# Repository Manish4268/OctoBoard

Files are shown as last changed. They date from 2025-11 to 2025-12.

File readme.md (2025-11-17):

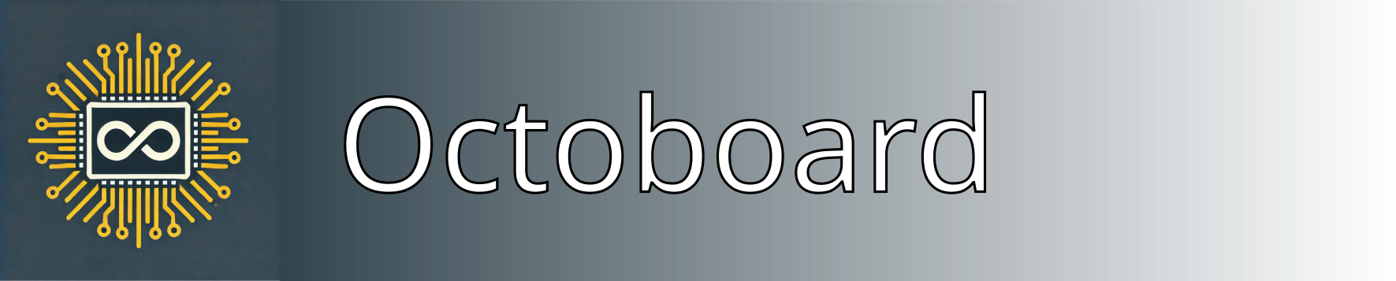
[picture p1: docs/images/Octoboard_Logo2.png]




# Maximum Power Point Tracker for Research-Level Solar Cells

## Overview
This repository documents the design, implementation, and operation of a massively parallel, low-cost Maximum Power Point Tracker (MPPT) for aging and degradation studies of perovskite solar cells. The system integrates custom-designed PCBs and software for efficient tracking and data logging.

**NEW: v2.0 System** - Production-ready system supporting 3 Raspberry Pis with up to 288 channels (72 samples). Features include configurable IV sweep intervals (1-1000 minutes), automated file transfer, persistent state management, optimized web dashboard, and automatic hardware detection for scalable deployment!

## Features

### Hardware

**Octoboards** (`Custom-designed PCBs`) - Source Measure Unit (SMU) functions
- 8 channels per board
- Modular and scalable design
- Support for multiple boards via I2C addressing
- **Current System**: 12 boards per Raspberry Pi = 96 channels
- **Total Capacity**: 3 RPis × 96 channels = **288 channels**

**Measurement Chuck**
- Allows up to 10 substrates (40 solar cells on "University of Marburg" cell layout)
- Aged in nitrogen atmosphere
- Compact design optimized for standard solar simulators
- Easy sample replacement without breaking atmosphere

### Software v2.0

**Dual-System Architecture:**

1. **RPi System** (`rpi_system/`)
   - Python-based control for 96 channels per RPi
   - Hourly automated IV sweeps
   - Real-time file transfer to Main PC
   - RESTful API for remote control
   - Sample configuration management (24 samples × 4 pixels)
   - **Simulation Mode** for development without hardware

2. **Main PC System** (`main_pc_system/`)
   - **Streamlit Dashboard** - Web-based control interface
   - **File Receiver** - Automated data collection from RPis
   - Real-time monitoring of all 3 RPis
   - Data visualization (IV curves, power curves)
   - Sample management and assignment
   - Data browser with file listings

**Key Capabilities:**
- ✅ 288 channels total (72 samples, 4 pixels each)
- ✅ Configurable IV sweep intervals (1-1000 minutes per sample)
- ✅ Automatic hardware detection (supports 1-12 Octoboards per RPi)
- ✅ Persistent state management via status files
- ✅ Optimized dashboard with pagination for 288+ channels
- ✅ Production-ready deployment with systemd service
- ✅ Comprehensive beginner's guide for Raspberry Pi setup
- ✅ Hourly IV sweep generation (1 file per channel)
- ✅ Automatic LAN-based file transfer
- ✅ Organized data storage: `SampleID/pixel/IV_timestamp.csv`
- ✅ Real-time dashboard monitoring
- ✅ Simulation mode for Windows development
- ✅ RESTful API control
- ✅ Multi-board management

### Integration
- Full Raspberry Pi compatibility (tested on RPi 4)
- Windows development support via simulation mode
- Network communication (LAN, no internet required)
- Modular and extensible architecture

## Repository Structure
```plaintext
├── docs/                                    # Documentation and images
├── hardware/                                # PCB designs and CAD files
│   ├── Measurement Chuck Housing CAD Design/
│   ├── Measurement Chuck PCB Design/
│   └── Octoboard PCB Design/
│   │   └── gerber.zip
│   ├── Octoboard PCB Design/
│   │   ├── DAC.kicad_sch
│   │   ├── octoboard.kicad_pcb
│   │   ├── octoboard.kicad_prl
│   │   ├── octoboard.kicad_pro
│   │   └── octoboard.kicad_sch
├── software/
│   ├── hardware/
│   │   ├── __init__.py
│   │   ├── channel.py
│   │   ├── constants.py
│   │   ├── i2c.py
│   │   ├── manager.py
│   │   ├── oboard.py
│   │   └── sdac.py
│   ├── tests/
│   │   ├── test_hardware.py
│   │   ├── test_logger.py
│   │   └── test_tracker.py
│   ├── __init__.py
│   ├── cli.py
│   ├── logger.py
│   ├── requirements.txt
│   └── setup.py
└── README.md
```

## Documentation

### 1. Hardware

#### **1.1 Octoboard**
The Octoboard is a custom-designed PCB that forms the core of the MPPT system, providing capabilities for maximum power point tracking in solar cell testing and evaluation.

**Key Components:**
- **MCP23017**: 16-bit I2C I/O expander for digital control
- **MCP4728**: 4-channel DAC for voltage control
- **ADS1115**: 16-bit ADC for precision measurement
- **LMV324**: Quad operational amplifiers for signal conditioning
- **74HC4051**: Analog multiplexers for efficient channel selection

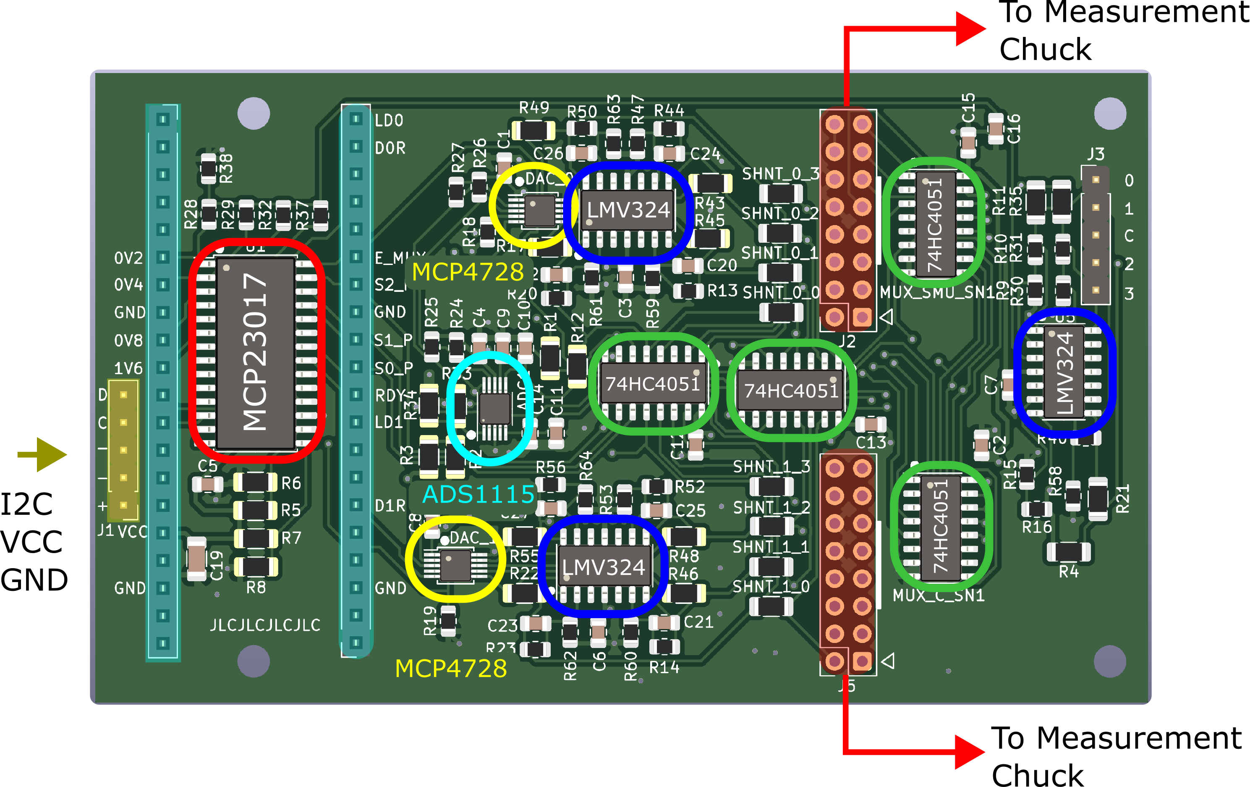
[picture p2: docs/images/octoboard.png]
Octoboard PCB Layout


#### Component Specifications

| Component | Type | Key Specifications | Datasheet |
|---|---|---|---|
| MCP4728 | DAC | 12-bit, 4-channel, I2C | [Datasheet](http://ww1.microchip.com/downloads/en/devicedoc/22187e.pdf) |
| ADS1115 | ADC | 16-bit, 4-channel, I2C | [Datasheet](https://www.ti.com/lit/gpn/ads1115) |
| LMV324 | Op-Amp | Rail-to-rail, low power | [Datasheet](https://www.onsemi.com/download/data-sheet/pdf/lmv321-d.pdf) |
| 74HC4051 | Multiplexer | 8-channel analog | [Datasheet](https://assets.nexperia.com/documents/data-sheet/74HC_HCT4051.pdf) |
| MCP23017 | I/O Expander | 16-bit, I2C | [Datasheet](https://ww1.microchip.com/downloads/aemDocuments/documents/APID/ProductDocuments/DataSheets/MCP23017-Data-Sheet-DS20001952.pdf) |

#### System Architecture
The MPPT system is designed with a hierarchical structure:
1. Central Raspberry Pi controller
2. Multiple Octoboards (8 channels each)
3. I2C communication backbone
4. Integrated sample holder with thermal management

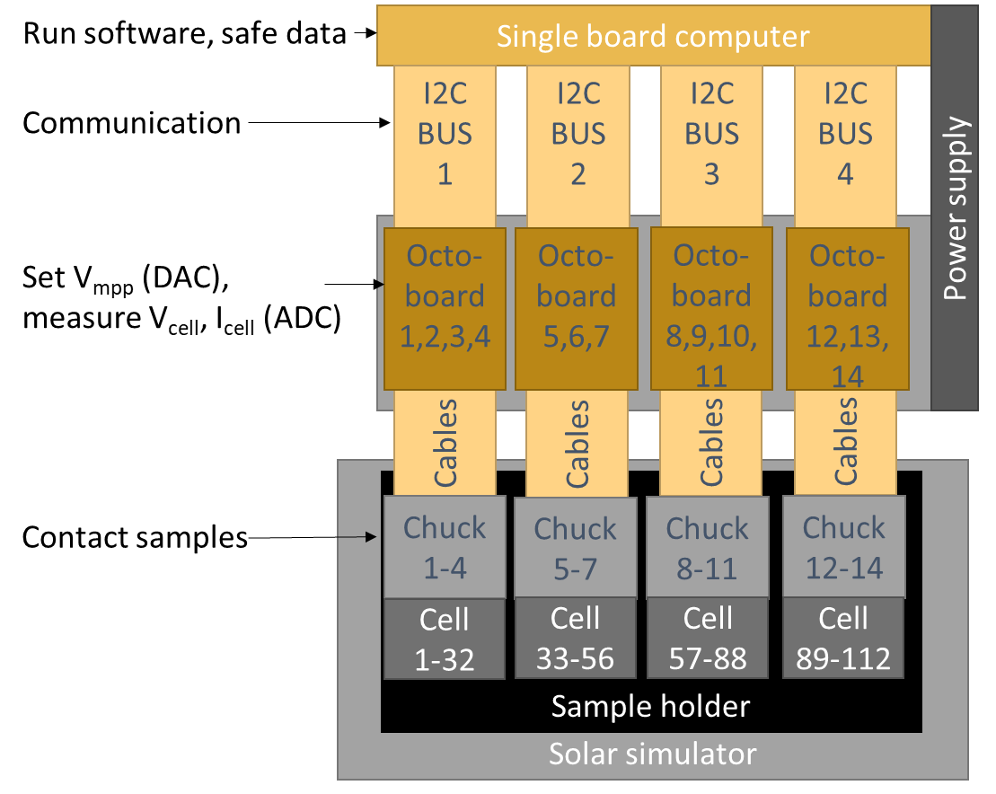
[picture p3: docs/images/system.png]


#### **1.2 Measurement Chuck**
The Measurement Chuck allows up to 10 substrates (40 solar cells on a "University of Marburg" cell layout) to be aged under a nitrogen atmosphere.
Due to its compact design, up to eight measurement chucks can be fit in a Solaronix SOLIXON A-45 solar simulator. 

**Operation & Handling**
To replace the substrates inside a chuck:
1. Disconnect the flat ribbon cables and nitrogen supply hoses (quick-connect couplings ensure that the remaining substrates stay in an N₂ atmosphere).
2. Transfer the chuck to a glovebox, where the cells can be exchanged by loosening the screws as shown in the video below.
3. Reinsert the newly equipped chuck into the sun simulator and attach it to the cables and supply hoses. 

<div style="display: flex; justify-content: flex-start;">
    
</div>

### 2. Software v2.0

## Quick Start

### System Components

**1. Raspberry Pi System** (`rpi_system/`)
- Controls 96 channels (12 Octoboards)
- Runs hourly IV sweeps automatically
- Transfers data to Main PC via LAN
- RESTful API for remote control

**2. Main PC System** (`main_pc_system/`)
- Web dashboard (Streamlit) for control
- File receiver for automated data collection
- Real-time monitoring of all RPis
- Data visualization and analysis

### Installation & Setup

#### Main PC System

```powershell
cd main_pc_system
.\start.bat  # Automatic setup and launch
```

Opens:
- File Receiver at `http://192.168.1.100:8000`
- Dashboard at `http://localhost:8501`

#### Raspberry Pi System

```bash
cd rpi_system

# For actual hardware
python api_server.py

# For simulation/testing (Windows)
$env:OCTOBOARD_SIMULATION="True"
python api_server.py
```

### Complete Documentation

- **[Main PC System README](main_pc_system/README.md)** - Setup, API endpoints, usage
- **[RPi System README](rpi_system/README.md)** - Hardware control, configuration
- **[Testing Guide](TESTING_GUIDE.md)** - Complete end-to-end testing procedures
- **[Project Structure](PROJECT_STRUCTURE.md)** - System architecture overview

## System Capacity

| Metric | Value |
|---|---|
| Raspberry Pis | 3 |
| Octoboards per RPi | 12 |
| Channels per RPi | 96 |
| **Total Channels** | **288** |
| Samples per RPi | 24 (4 pixels each) |
| **Total Sample Capacity** | **72** |
| IV Sweep Frequency | Every 1 hour |
| Files Generated | 96 per hour per RPi |

## Network Configuration

| Device | IP Address | Port | Role |
|---|---|---|---|
| Main PC | 192.168.1.100 | 8000 (Receiver) | Control center |
| Main PC | 192.168.1.100 | 8501 (Dashboard) | Web interface |
| RPi 1 | 192.168.1.101 | 8001 | Channels 0-95 |
| RPi 2 | 192.168.1.102 | 8001 | Channels 0-95 |
| RPi 3 | 192.168.1.103 | 8001 | Channels 0-95 |

## Data Flow

```
┌─────────────┐
│   RPi 1-3   │ ──► Hourly IV Sweeps (96 channels each)
│ (Octoboards)│       │
└─────────────┘       │
                      ▼
              ┌──────────────┐
              │  Generate    │ ──► 4 CSV files per sample
              │  IV Files    │       (pixels a, b, c, d)
              └──────────────┘
                      │
                      ▼
              ┌──────────────┐
              │  HTTP POST   │ ──► Transfer over LAN
              │  to Main PC  │
              └──────────────┘
                      │
                      ▼
         ┌────────────────────────┐
         │  Main PC File Receiver │
         │  Organizes & Stores    │
         └────────────────────────┘
                      │
                      ▼
    C:/OctoBoard_Data/
    └── SampleID/
        ├── a/
        │   └── IV_timestamp.csv
        ├── b/
        ├── c/
        └── d/
```

### 2. Software (Legacy)

#### Installation

1. Clone the repository:
```bash
git clone https://github.com/H2020DiamondEU/octoboard.git
cd octoboard
```

2. Install dependencies:
```bash
pip install -r software/requirements.txt
```

3. Install the package:
```bash
pip install -e .
```

#### Usage

1. Basic operation:
```python
from software import OBoardManager

# Initialize manager with I2C bus number
manager = OBoardManager(i2c_num=1)

# Start MPP tracking on all channels
manager.cycle_all_channels(iterations_per_channel=10)
```

2. Command-line interface:
```bash
python -m software.cli 1  # Start tracking on I2C bus 1
```

### 3. Data Management

Data is stored in CSV format with the following structure:
- Location: `data/[board_id]_channel_[n]_data.csv`
- Format: timestamp, voltage, current, power, temperature

### 4. Troubleshooting

Common issues and solutions:
1. I2C Communication Errors
   - Check bus number and device addresses
   - Verify cable connections
   - Check for address conflicts

2. Measurement Instability
   - Verify power supply stability
   - Check contact resistance

## License
This project is licensed under the MIT License. See `LICENSE` for details.

## Links
- [Project Website](https://diamond-horizon.eu/)
- [European Commission Project Page](https://cordis.europa.eu/project/id/101084124)
- [Deliverable Documentation](https://ec.europa.eu/research/participants/documents/downloadPublic?documentIds=080166e50d1470c5&appId=PPGMS)

## Contact
For further information on integrating this measurement system into your PV lab, please contact:
- **Lukas Wagner**, Physics of Solar Energy Conversion Group, Philipps-University Marburg, Germany.
- **Clemens Baretzky**, Fraunhofer Institute for Solar Energy Systems ISE, Germany.

<div style="display: flex; justify-content: flex-start;">
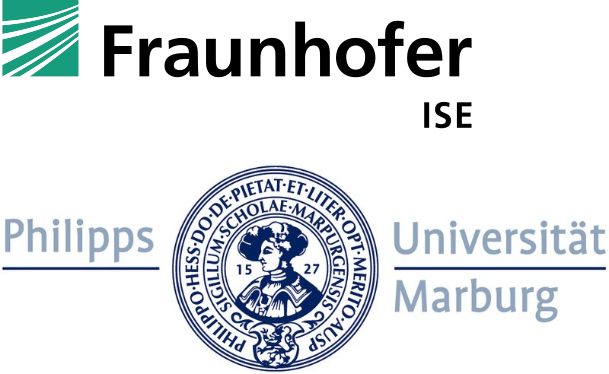
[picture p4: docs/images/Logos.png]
    
</div> 

## Acknowledgments
This design was developed at the **University of Marburg** and **Fraunhofer ISE**.
The project is funded by the European Union in the Horizon 2.5. Climate, Energy and Mobility programme under Grant Agreement No. 101084124. Views and opinions expressed are however those of the author(s) only and do not necessarily reflect those of the European Union. Neither the European Union nor the granting authority can be held responsible for them.

<div style="display: flex; justify-content: flex-start;">
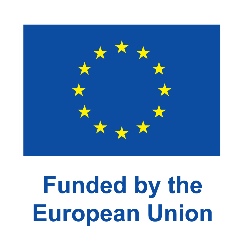
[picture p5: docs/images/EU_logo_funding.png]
    
</div>

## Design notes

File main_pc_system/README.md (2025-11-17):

# OctoBoard Main PC System

Control center for managing 3 Raspberry Pis with 288 channels (72 samples) for solar cell testing.

## System Overview

- **Total Capacity**: 3 RPis × 96 channels = 288 channels
- **Sample Capacity**: 72 samples (24 per RPi, 4 pixels per sample)
- **Data Generation**: Hourly IV sweeps per channel (96 files/hour/RPi)
- **Communication**: LAN-based REST API (192.168.1.x network)

## Components

### 1. File Receiver (`file_receiver.py`)
FastAPI server that receives IV measurement files from RPis.

**Features:**
- HTTP POST endpoint for file uploads
- Automatic directory structure creation
- File validation and statistics tracking
- Sample management endpoints

**Endpoints:**
- `POST /upload` - Receive IV files from RPis
- `GET /ping` - Health check
- `GET /stats` - Get receiver statistics
- `GET /samples` - List all samples
- `GET /sample/{sample_id}` - Get files for specific sample

### 2. Dashboard (`dashboard.py`)
Streamlit-based web interface for system control and monitoring.

**Features:**
- Real-time RPi status monitoring
- New sample measurement configuration
- Active measurement management
- Data browser with file listings
- IV curve visualization with Plotly

**Tabs:**
1. **New Measurement** - Configure and start new sample measurements
2. **Active Measurements** - Monitor and control running measurements
3. **Data Browser** - Browse stored IV files by sample/pixel
4. **Data Visualization** - Plot IV and power curves

## Installation

### Requirements
- Python 3.9 or higher
- Windows 10/11 (or Linux/Mac with path adjustments)

### Setup

```powershell
# Navigate to main_pc_system directory
cd C:\Users\ManishJadhav\OctoBoard\main_pc_system

# Create virtual environment
python -m venv venv

# Activate virtual environment
.\venv\Scripts\Activate.ps1

# Install dependencies
pip install -r requirements.txt
```

## Running the System

### 1. Start File Receiver

```powershell
# Terminal 1
cd C:\Users\ManishJadhav\OctoBoard\main_pc_system
.\venv\Scripts\Activate.ps1
python -m uvicorn file_receiver:app --host 0.0.0.0 --port 8000
```

**Expected Output:**
```
INFO:     Started server process
INFO:     Waiting for application startup.
INFO:     Application startup complete.
INFO:     Uvicorn running on http://0.0.0.0:8000
```

### 2. Start Dashboard

```powershell
# Terminal 2 (new terminal)
cd C:\Users\ManishJadhav\OctoBoard\main_pc_system
.\venv\Scripts\Activate.ps1
streamlit run dashboard.py
```

**Expected Output:**
```
You can now view your Streamlit app in your browser.
Local URL: http://localhost:8501
Network URL: http://192.168.1.100:8501
```

## Network Configuration

### Main PC
- **IP Address**: `192.168.1.100`
- **File Receiver**: Port `8000`
- **Dashboard**: Port `8501`

### Raspberry Pis
- **RPi 1**: `192.168.1.101:8001` (Channels 0-95, Samples 1-24)
- **RPi 2**: `192.168.1.102:8001` (Channels 0-95, Samples 25-48)
- **RPi 3**: `192.168.1.103:8001` (Channels 0-95, Samples 49-72)

## Data Storage

### Directory Structure
```
C:/OctoBoard_Data/
├── Sample_001/
│   ├── a/
│   │   ├── IV_20240101_120000.csv
│   │   ├── IV_20240101_130000.csv
│   │   └── ...
│   ├── b/
│   ├── c/
│   └── d/
├── Sample_002/
│   ├── a/
│   ├── b/
│   ├── c/
│   └── d/
└── ...
```

### File Format
Each IV file is a CSV with columns:
- `voltage` - Applied voltage (V)
- `current` - Measured current (A)
- `power` - Calculated power (W)
- `timestamp` - Measurement timestamp

## Usage Guide

### Starting a New Measurement

1. Open dashboard at `http://localhost:8501`
2. Go to **"New Measurement"** tab
3. Fill in sample information:
   - Sample ID (unique identifier)
   - Cell area (cm²)
   - Current limit (mA)
4. Configure IV sweep parameters:
   - Start/Stop voltage
   - Voltage step
   - Settle time
5. Select RPi and channel slot
6. Click **"Start Measurement"**

### Monitoring Active Measurements

1. Go to **"Active Measurements"** tab
2. View all running measurements across RPis
3. Stop measurements using **"Stop"** button

### Browsing Data

1. Go to **"Data Browser"** tab
2. Select sample from dropdown
3. View file counts for each pixel (a, b, c, d)
4. See latest file timestamps

### Visualizing Data

1. Go to **"Data Visualization"** tab
2. Select sample and pixel
3. Choose specific IV file to plot
4. View IV curve and power curve
5. See key metrics (max power, voltage at MPP)

## Troubleshooting

### File Receiver Not Starting
```powershell
# Check if port 8000 is in use
netstat -ano | findstr :8000

# Kill process if needed
taskkill /PID <process_id> /F
```

### Dashboard Cannot Connect to RPis
- Verify RPis are powered on and running API servers
- Check network connectivity: `ping 192.168.1.101`
- Ensure firewall allows ports 8001-8003
- Check RPi API server logs

### No Data Appearing
- Verify file receiver is running on port 8000
- Check `C:/OctoBoard_Data/` directory permissions
- Review file receiver logs for upload errors
- Ensure RPis have correct Main PC IP configured

### Dashboard Shows Offline RPis
- Confirm RPi API servers are running
- Test RPi endpoints manually:
  ```powershell
  curl http://192.168.1.101:8001/status
  ```
- Check network switches and cables
- Verify IP addresses in dashboard match RPi configuration

## API Documentation

### File Receiver API

**POST /upload**
```json
{
  "file": "<binary file data>",
  "rpi_id": "rpi_1",
  "sample_id": "Sample_001",
  "pixel": "a"
}
```

**Response:**
```json
{
  "status": "success",
  "message": "File uploaded successfully",
  "file_path": "C:/OctoBoard_Data/Sample_001/a/IV_20240101_120000.csv",
  "file_size": 12345
}
```

**GET /stats**
```json
{
  "files_received": 1250,
  "total_bytes": 15728640,
  "last_received": "2024-01-01T12:00:00"
}
```

## Development Notes

### Testing Without RPis
The system can be tested with mock RPis running in simulation mode:

```powershell
# Start mock RPi (simulate RPi 1)
cd ..\rpi_system
$env:OCTOBOARD_SIMULATION="True"
python api_server.py
```

### Customization

**Change data directory:**
Edit `dashboard.py` and `file_receiver.py`:
```python
DATA_ROOT = Path("D:/MyData")  # Change path
```

**Modify RPi IP addresses:**
Edit `dashboard.py`:
```python
RPIS = {
    "RPi 1": {"url": "http://192.168.2.101:8001", "id": "rpi_1"},
    # ...
}
```

**Adjust sweep interval:**
Edit `rpi_system/api_server.py`:
```python
IV_SWEEP_INTERVAL_HOURS = 2  # Change from 1 to 2 hours
```

## Performance

- **File Transfer Rate**: ~100 files/second
- **Dashboard Refresh**: ~1-2 seconds for 3 RPis
- **Storage**: ~10 KB per IV file, ~24 MB/day/sample (hourly sweeps)
- **Memory Usage**: Dashboard ~200 MB, File Receiver ~100 MB

## Safety Features

- File validation before storage
- Automatic directory creation
- Graceful handling of offline RPis
- Statistics tracking for monitoring
- No internet dependency (LAN only)

## Future Enhancements

- Database integration (SQLite/PostgreSQL)
- Email alerts for measurement completion
- Automatic data backup
- Multi-file IV curve comparison
- Export to Excel/PDF reports
- User authentication
- Measurement scheduling
- Data compression for long-term storage

## Support

For issues or questions:
1. Check troubleshooting section above
2. Review logs in terminal windows
3. Verify network configuration
4. Test individual components separately

## License

Part of OctoBoard project - Solar cell MPPT testing system.

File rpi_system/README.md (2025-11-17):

# Raspberry Pi System

This code runs on each Raspberry Pi to control 96 channels (12 Octoboards).

## Hardware Configuration

- **12 Octoboards** per Raspberry Pi
- **96 channels** total (12 × 8)
- **24 samples** capacity (each sample uses 4 channels for 4 pixels)
- **I2C Bus:** Typically bus 1
- **I2C Address Offsets:** 0-11 (for 12 boards)

## Features

- Controls 96 channels via 12 Octoboards
- Handles 24 samples simultaneously (4 pixels each)
- Hourly IV sweep generation (every 1 hour)
- Automatic file transfer to Main PC via LAN
- REST API for remote control from Main PC
- Simulation mode for testing without hardware

## Installation

```bash
cd rpi_system/
pip install -r requirements.txt
```

## Configuration

Set environment variables:

```bash
export RPI_ID=rpi_1              # or rpi_2, rpi_3
export OCTOBOARD_I2C_BUS=1       # I2C bus number
export MAIN_PC_IP=192.168.1.100  # Main PC IP address
export API_PORT=8001              # API server port
```

## Running

### Production Mode (on Raspberry Pi):

```bash
python api_server.py
```

### Simulation Mode (for testing on Windows/Mac):

```bash
export OCTOBOARD_SIMULATION=True
python api_server.py
```

## API Endpoints

### Status and Info

- `GET /` - API information
- `GET /status` - RPi status
- `GET /channels` - List all 96 channels (24 sample slots)

### Measurements

- `POST /measurement/start` - Start measuring a sample
- `POST /measurement/stop/{sample_id}` - Stop measuring a sample
- `GET /measurement/{sample_id}` - Get sample measurement status

## Sample Configuration

Each sample occupies 4 consecutive channels for 4 pixels (a, b, c, d):

```json
{
  "sample_id": "Sample_001",
  "start_channel": 0,
  "cell_area": 0.09,
  "current_limit": 50,
  "start_voltage": 0.0,
  "stop_voltage": 1.2,
  "voltage_step": 0.01,
  "settle_time": 0.1,
  "measurement_type": "iv_sweep"
}
```

### Channel Allocation:

- Sample 1: channels 0-3 (pixels a, b, c, d)
- Sample 2: channels 4-7 (pixels a, b, c, d)
- ...
- Sample 24: channels 92-95 (pixels a, b, c, d)

## Hourly IV Sweeps

- Configured in `software/hardware/constants.py`: `IV_SWEEP_INTERVAL_HOURS = 1`
- Runs IV sweep for all active samples every hour
- Generates timestamped files: `IV_2025-11-17_10-00-00.csv`
- Automatically transfers files to Main PC

## File Transfer

Files are sent to Main PC via HTTP POST:
- **URL:** `http://{MAIN_PC_IP}:8000/upload`
- **Method:** POST with multipart/form-data
- **Timeout:** 30 seconds (configurable)

## Directory Structure

```
rpi_system/
├── api_server.py              # Main API server
├── software/                  # Hardware control code
│   ├── __init__.py
│   ├── cli.py
│   ├── logger.py
│   └── hardware/
│       ├── channel.py         # Single channel control
│       ├── oboard.py          # Single board (8 channels)
│       ├── manager.py         # Multi-board manager
│       ├── constants.py       # Configuration
│       ├── i2c.py             # I2C interface
│       ├── sdac.py            # Software DAC
│       └── mock_hardware.py   # Simulation mode
├── requirements.txt           # Dependencies
└── README.md                  # This file
```

## Troubleshooting

### RPi can't detect all 12 boards:
```bash
# Check I2C devices
i2cdetect -y 1
```

### Main PC connection fails:
- Verify Main PC file receiver is running
- Check network connectivity: `ping 192.168.1.100`
- Check firewall settings

### Simulation mode not working:
```bash
# Make sure simulation flag is set
echo $OCTOBOARD_SIMULATION
export OCTOBOARD_SIMULATION=True
```

## Network Requirements

- **LAN/Ethernet connection** (no internet required)
- **Static IP recommended:** 192.168.1.101-103
- **Open Ports:**
  - 8001: RPi API server
  - 8000: Main PC file receiver (outgoing)

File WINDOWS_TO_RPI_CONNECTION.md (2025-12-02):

# 🔌 How to Connect to Raspberry Pi from Windows

## 📋 What You Need

### Hardware
- ✅ Raspberry Pi (any model with GPIO pins)
- ✅ Ethernet cable connecting RPi to your laptop/network
- ✅ Power supply for RPi (5V, 2.5A+)
- ✅ MicroSD card with Raspberry Pi OS installed
- ⚠️ Optional: HDMI monitor + keyboard (for initial setup)

### Software for Windows
We'll install these step by step below:
1. **PuTTY** - SSH client to connect to RPi
2. **WinSCP** - File transfer tool
3. **VS Code** (optional) - For editing code remotely
4. **IP Scanner** - To find your RPi

---

## 🎯 Step 1: Install Required Software

### Install PuTTY (SSH Client)

**What is PuTTY?**
PuTTY lets you control the Raspberry Pi using command line from your Windows PC.

**Download:**
1. Go to: https://www.putty.org/
2. Click: **Download PuTTY**
3. Download: `putty-64bit-0.xx-installer.msi`
4. Run the installer
5. Click **Next** → **Install** → **Finish**

**Where it is:** Start Menu → PuTTY → PuTTY

---

### Install WinSCP (File Transfer)

**What is WinSCP?**
WinSCP lets you drag-and-drop files between Windows and Raspberry Pi (like Windows Explorer).

**Download:**
1. Go to: https://winscp.net/eng/download.php
2. Download: **Installation package**
3. Run installer
4. Click **Next** → **Next** → **Install** → **Finish**

**Where it is:** Start Menu → WinSCP

---

### Install Advanced IP Scanner (Find RPi)

**What is Advanced IP Scanner?**
Scans your network to find all connected devices, including your Raspberry Pi.

**Download:**
1. Go to: https://www.advanced-ip-scanner.com/
2. Click **Download**
3. Run `advanced_ip_scanner.exe`
4. No installation needed - it runs directly!

---

### Install VS Code with Remote SSH (Optional, for Advanced Users)

**What is VS Code Remote SSH?**
Edit code on Raspberry Pi directly from VS Code on Windows - super convenient for debugging!

**Download VS Code:**
1. Go to: https://code.visualstudio.com/
2. Download Windows version
3. Install with default settings

**Install Remote SSH Extension:**
1. Open VS Code
2. Click Extensions icon (left sidebar, squares icon)
3. Search: **Remote - SSH**
4. Click **Install** on "Remote - SSH" by Microsoft
5. Done!

---

## 🔍 Step 2: Find Your Raspberry Pi's IP Address

### Method 1: Using Advanced IP Scanner (Easiest!)

1. **Run Advanced IP Scanner**
2. Click **Scan** (big green button)
3. Wait 30 seconds for scan to complete
4. **Look for device named:**
   - `raspberrypi` or
   - `Raspberry Pi Foundation` (in Manufacturer column)
5. **Note the IP address** (e.g., `192.168.1.150`)

**Screenshot of what to look for:**
```
IP Address       Name              Manufacturer
192.168.1.1      router            TP-Link
192.168.1.100    DESKTOP-ABC       Microsoft
192.168.1.150    raspberrypi       Raspberry Pi Foundation  ← THIS ONE!
```

---

### Method 2: Using Your Router

1. Open browser
2. Go to router admin page:
   - Usually: `192.168.1.1` or `192.168.0.1`
   - Try: `http://192.168.1.1`
3. Login (check router sticker for password)
4. Find "Connected Devices" or "DHCP Clients"
5. Look for "raspberrypi" - note its IP

---

### Method 3: Using Windows Command Prompt

```powershell
# Open PowerShell or Command Prompt
arp -a

# Look for MAC addresses starting with:
# b8-27-eb or dc-a6-32 (Raspberry Pi MAC addresses)
```

---

### Method 4: Connect Monitor to RPi

If all else fails:
1. Connect HDMI monitor to RPi
2. Connect keyboard
3. Power on RPi
4. Login (username: `pi`, password: `raspberry`)
5. Type command:
```bash
hostname -I
```
6. You'll see the IP address!

---

## 🔐 Step 3: Connect Using PuTTY (SSH)

### First Time Connection

1. **Open PuTTY**
2. In "Host Name" box, type: `pi@192.168.1.150` (use YOUR RPi's IP)
3. Port: `22` (default)
4. Connection type: **SSH**
5. Click **Open**

**You'll see a security alert:**
```
PuTTY Security Alert
The server's host key is not cached...
Do you trust this host?
```
6. Click **Yes** (this is normal for first connection)

**Login:**
```
login as: pi
password: raspberry
```
**⚠️ When typing password, you won't see any characters - this is normal! Just type and press Enter.**

**Success!** You should see:
```
Linux raspberrypi 5.10.63-v7l+ #1459 SMP Wed Oct 6 16:41:57 BST 2021 armv7l

pi@raspberrypi:~ $
```

---

### PuTTY Settings to Save

**To save your connection:**
1. Before clicking Open
2. Type a name in "Saved Sessions" (e.g., "My RPi")
3. Click **Save**
4. Next time: Double-click "My RPi" to connect instantly!

**Useful PuTTY Settings:**
- Window → Columns: `120`, Rows: `40` (bigger window)
- Window → Colours → Use system colours: **Uncheck** (better colors)
- Terminal → Bell → **None** (no annoying beeps)

---

## 📁 Step 4: Transfer Files Using WinSCP

### First Time Setup

1. **Open WinSCP**
2. Click **New Site**
3. File protocol: **SFTP**
4. Host name: `192.168.1.150` (YOUR RPi IP)
5. Port: `22`
6. User name: `pi`
7. Password: `raspberry`
8. Click **Save**
9. Give it a name: "My RPi"
10. Click **OK**

### Connect and Transfer Files

1. **Click Login** (or double-click saved session)
2. If asked about host key, click **Yes**

**You'll see two panels:**
- **Left:** Your Windows files
- **Right:** Raspberry Pi files

**Transfer files:**
- **Windows → RPi:** Drag from left to right
- **RPi → Windows:** Drag from right to left
- **Create folder:** Right panel → Right-click → New → Directory
- **Delete file:** Right-click → Delete

**Shortcuts:**
- **F5** - Refresh
- **F6** - Move/Rename
- **Delete** - Delete file
- **Ctrl+Alt+N** - Open PuTTY terminal

---

## 💻 Step 5: Use VS Code for Remote Development (Advanced)

### Setup Remote Connection

1. **Open VS Code**
2. Press **F1** (or Ctrl+Shift+P)
3. Type: `Remote-SSH: Connect to Host`
4. Click it
5. Click **+ Add New SSH Host**
6. Type: `ssh pi@192.168.1.150`
7. Press Enter
8. Select config file: `C:\Users\YourName\.ssh\config` (first option)
9. Click **Connect**

**First time:**
- Select platform: **Linux**
- Trust host: **Continue**
- Enter password: `raspberry`

**Success!** VS Code is now connected to your RPi!

### Edit Files Remotely

1. Click **Explorer** icon (top left)
2. Click **Open Folder**
3. Type: `/home/pi/OctoBoard/rpi_system`
4. Click **OK**
5. Enter password: `raspberry`

**Now you can:**
- ✅ Edit files directly on RPi
- ✅ Save changes (Ctrl+S)
- ✅ Use VS Code's debugging tools
- ✅ Run terminal commands (View → Terminal)

---

## 🐛 Step 6: Debugging on Raspberry Pi

### View Logs in Real-Time

**In PuTTY:**
```bash
# See API server output
# (If running with start_rpi.sh, logs appear in same terminal)

# See system logs
sudo journalctl -f

# See specific service logs (if using systemd)
sudo journalctl -u octoboard -f

# Press Ctrl+C to stop viewing logs
```

### Check What's Running

```bash
# See all Python processes
ps aux | grep python

# Check specific port
sudo lsof -i :8001

# Check if API server is responding
curl http://localhost:8001/status
```

### Debug Connection Issues

**Test if RPi can reach Main PC:**
```bash
# Ping Main PC
ping 192.168.1.100

# Test file receiver
curl http://192.168.1.100:8000/ping
```

**Test if Main PC can reach RPi:**
```powershell
# In Windows PowerShell
curl http://192.168.1.150:8001/status
```

### View Python Errors

**In PuTTY (while API server is running):**
- All errors appear in the terminal
- Look for lines starting with:
  - `ERROR:`
  - `Traceback:`
  - `Exception:`

**Copy error messages:**
- Select text with mouse in PuTTY
- Text is automatically copied!
- Right-click in any program to paste

---

## 🔧 Common Debugging Tasks

### Check I2C Devices

```bash
# See connected I2C devices
sudo i2cdetect -y 1

# Should show Octoboard addresses:
# 20 (MCP23017), 48 (ADS1115), 60-61 (MCP4728)
```

### Test Python Code

```bash
# Activate virtual environment
cd /home/pi/rpi_system
source venv/bin/activate

# Run Python commands
python3 -c "print('Hello from RPi!')"

# Test hardware detection
python3 -c "
from software import get_hardware_classes
OBoardManager, _, _, _ = get_hardware_classes()
manager = OBoardManager(i2c_num=1)
print(f'Found {len(manager.oboards)} boards')
"
```

### Edit Configuration Files

**Using nano (built-in text editor):**
```bash
# Edit constants file
nano software/hardware/constants.py

# Navigate: Arrow keys
# Save: Ctrl+O → Enter
# Exit: Ctrl+X
```

**Or use WinSCP:**
1. Navigate to file in right panel
2. Right-click → Edit
3. Edit in Notepad
4. Save (Ctrl+S)
5. Close Notepad
6. WinSCP uploads automatically!

---

## 🎯 Recommended Workflow

### For Debugging:

1. **PuTTY (Terminal 1)** - Run API server
   ```bash
   cd /home/pi/rpi_system
   source venv/bin/activate
   ./start_rpi.sh
   ```

2. **PuTTY (Terminal 2)** - For commands/debugging
   - Open another PuTTY connection
   - Run test commands
   - Check logs
   - Monitor system

3. **WinSCP** - Transfer/edit files
   - Drag files to RPi
   - Quick edits
   - View logs

4. **VS Code** (Optional) - For heavy coding
   - Edit multiple files
   - Search/replace across project
   - Git integration
   - Debugging tools

---

## 📝 Quick Reference Commands

### Connection Commands

```powershell
# Windows PowerShell - Ping RPi
ping 192.168.1.150

# Windows PowerShell - SSH (if you have OpenSSH)
ssh pi@192.168.1.150

# Windows PowerShell - Copy files
scp -r C:\OctoBoard\rpi_system pi@192.168.1.150:/home/pi/
```

### RPi Commands

```bash
# Basic navigation
pwd              # Print current directory
ls               # List files
cd foldername    # Change directory
cd ..            # Go up one level
cd ~             # Go to home directory

# File operations
cat filename     # View file content
nano filename    # Edit file
cp file1 file2   # Copy file
mv old new       # Move/rename
rm filename      # Delete file

# System
sudo reboot      # Restart RPi
sudo shutdown -h now  # Shutdown
exit             # Logout

# Network
hostname -I      # Show IP address
ifconfig         # Network info
ping google.com  # Test internet
```

---

## 🆘 Troubleshooting

### Can't Connect with PuTTY

**Error: "Network error: Connection refused"**
- RPi not powered on
- Wrong IP address
- SSH not enabled on RPi

**Solution:**
```bash
# Enable SSH (need monitor/keyboard on RPi)
sudo raspi-config
# → Interface Options → SSH → Enable
```

**Or create SSH file:**
1. Remove SD card from RPi
2. Insert into Windows PC
3. Open boot drive
4. Create empty file named `ssh` (no extension)
5. Put SD card back in RPi

---

### Can't Transfer Files with WinSCP

**Error: "Authentication failed"**
- Wrong password
- SSH not enabled

**Error: "Permission denied"**
- Create folder in `/home/pi/` not `/root/`
- Or use: `sudo chown -R pi:pi /path/to/folder`

---

### Lost RPi IP Address

**Quick way to find it again:**
1. Open Advanced IP Scanner
2. Click Scan
3. Look for "raspberrypi"

**Or check router's DHCP list**

---

## 📚 Useful Resources

**PuTTY Documentation:**
- https://www.putty.org/

**WinSCP Guide:**
- https://winscp.net/eng/docs/start

**Raspberry Pi SSH:**
- https://www.raspberrypi.com/documentation/computers/remote-access.html

**VS Code Remote SSH:**
- https://code.visualstudio.com/docs/remote/ssh

---

## ✅ You're Ready!

**You now have:**
- ✅ PuTTY - Control RPi via command line
- ✅ WinSCP - Transfer files easily
- ✅ IP Scanner - Find RPi on network
- ✅ VS Code (optional) - Professional editing

**Start here:** Follow `RPi_BEGINNER_GUIDE.md` with these tools!

**Need help?**
- PuTTY is your main tool for running commands
- WinSCP for moving files
- VS Code for editing code remotely (advanced)

🎉 **Happy Raspberry Pi coding!**

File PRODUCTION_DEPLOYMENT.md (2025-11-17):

# OctoBoard Production Deployment Guide

## 🚀 Deploying to Real Raspberry Pi

### Prerequisites on Raspberry Pi
```bash
# Update system
sudo apt update && sudo apt upgrade -y

# Install Python 3.9+
sudo apt install python3 python3-pip python3-venv -y

# Enable I2C
sudo raspi-config
# → Interface Options → I2C → Enable

# Verify I2C is enabled
ls /dev/i2c-*
# Should show: /dev/i2c-1

# Install I2C tools to scan devices
sudo apt install i2c-tools -y

# Scan I2C bus (run this AFTER connecting Octoboards)
sudo i2cdetect -y 1
```

### Step 1: Transfer Code to Raspberry Pi

**Option A: Using Git (Recommended)**
```bash
# On Raspberry Pi
cd /home/pi
git clone https://github.com/Manish4268/OctoBoard.git
cd OctoBoard/rpi_system
```

**Option B: Using SCP from Windows**
```powershell
# On Windows (from OctoBoard folder)
scp -r rpi_system pi@<RPI_IP_ADDRESS>:/home/pi/
```

### Step 2: Setup Virtual Environment on RPi

```bash
# On Raspberry Pi
cd /home/pi/OctoBoard/rpi_system

# Create virtual environment
python3 -m venv venv

# Activate venv
source venv/bin/activate

# Install dependencies
pip install --upgrade pip
pip install -r requirements.txt

# Install I2C libraries
pip install adafruit-circuitpython-busdevice
pip install adafruit-circuitpython-mcp4728
pip install adafruit-circuitpython-ads1x15
pip install adafruit-circuitpython-mcp230xx
```

### Step 3: Configure for Production

**Edit `software/hardware/constants.py`:**
```python
# Change from localhost to actual Main PC IP
MAIN_PC_IP = "192.168.1.100"  # Your Main PC's IP address
MAIN_PC_PORT = 8000
```

**Set environment variables:**
```bash
# On Raspberry Pi
export RPI_ID="rpi_1"           # or rpi_2, rpi_3
export OCTOBOARD_SIMULATION="False"  # IMPORTANT: Turn off simulation!
export OCTOBOARD_I2C_BUS="1"    # Default I2C bus
export API_PORT="8001"          # 8001 for RPi1, 8002 for RPi2, 8003 for RPi3
```

### Step 4: Test Hardware Detection

```bash
# Activate venv
source venv/bin/activate

# Run test to detect boards
python -c "
from software import get_hardware_classes
OBoardManager, _, _, _ = get_hardware_classes()
manager = OBoardManager(i2c_num=1)
print(f'Detected {len(manager.oboards)} Octoboards')
print(f'Total channels: {len(manager.oboards) * 8}')
"
```

**Expected output:**
```
Found I2C devices at addresses: {32, 72, 96, 97, ...}
Successfully initialized OBoard with I2C offset 0
Detected 1 Octoboards
Total channels: 8
```

### Step 5: Test API Server

```bash
# Start server
export RPI_ID="rpi_1"
export OCTOBOARD_SIMULATION="False"
export API_PORT="8001"
python api_server.py
```

**Expected output:**
```
[rpi_1] Starting up...
[rpi_1] Simulation Mode: False
[rpi_1] Total Channels: 96
[rpi_1] Sample Capacity: 24
Found I2C devices at addresses: {32, 72, 96, 97}
Successfully initialized OBoard with I2C offset 0
[rpi_1] Initialized 1 boards
[rpi_1] Scheduler started (per-sample intervals)
INFO:     Uvicorn running on http://0.0.0.0:8001
```

### Step 6: Configure Main PC

**Edit `main_pc_system/dashboard.py`:**
```python
# Change RPi URLs from localhost to actual IPs
RPIS = {
    "RPi 1": {"url": "http://192.168.1.101:8001", "id": "rpi_1"},
    "RPi 2": {"url": "http://192.168.1.102:8002", "id": "rpi_2"},
    "RPi 3": {"url": "http://192.168.1.103:8003", "id": "rpi_3"},
}
```

### Step 7: Create Systemd Service (Auto-start on boot)

**Create service file:**
```bash
sudo nano /etc/systemd/system/octoboard.service
```

**Service content:**
```ini
[Unit]
Description=OctoBoard RPi API Server
After=network.target

[Service]
Type=simple
User=pi
WorkingDirectory=/home/pi/OctoBoard/rpi_system
Environment="RPI_ID=rpi_1"
Environment="OCTOBOARD_SIMULATION=False"
Environment="OCTOBOARD_I2C_BUS=1"
Environment="API_PORT=8001"
ExecStart=/home/pi/OctoBoard/rpi_system/venv/bin/python api_server.py
Restart=always
RestartSec=10

[Install]
WantedBy=multi-user.target
```

**Enable and start service:**
```bash
# Reload systemd
sudo systemctl daemon-reload

# Enable service (start on boot)
sudo systemctl enable octoboard

# Start service now
sudo systemctl start octoboard

# Check status
sudo systemctl status octoboard

# View logs
sudo journalctl -u octoboard -f
```

### Step 8: Network Configuration

**On Main PC (Windows):**
1. Open Firewall settings
2. Allow inbound connections on port 8000
3. Note your PC's IP address: `ipconfig` → IPv4 Address

**On Raspberry Pi:**
```bash
# Check if RPi can reach Main PC
ping 192.168.1.100

# Test file receiver
curl http://192.168.1.100:8000/ping
```

### Step 9: Verify Everything Works

**Checklist:**
- [ ] I2C enabled on RPi: `ls /dev/i2c-*`
- [ ] Octoboards detected: `sudo i2cdetect -y 1`
- [ ] API server running: `curl http://localhost:8001/status`
- [ ] Main PC reachable from RPi: `ping 192.168.1.100`
- [ ] File receiver running on Main PC
- [ ] Dashboard can connect to RPi
- [ ] Sample measurement creates files
- [ ] Files transferred to Main PC

## 🔧 Troubleshooting

### Issue: No I2C devices detected
```bash
# Check I2C is enabled
sudo raspi-config

# Check I2C modules loaded
lsmod | grep i2c

# Manual load
sudo modprobe i2c-dev
```

### Issue: Permission denied on I2C
```bash
# Add user to i2c group
sudo usermod -a -G i2c pi
sudo reboot
```

### Issue: Import errors
```bash
# Reinstall in venv
source venv/bin/activate
pip install --force-reinstall -r requirements.txt
```

### Issue: Cannot connect to Main PC
```bash
# Check firewall on Windows
# Check IP address is correct
# Test with: curl http://<MAIN_PC_IP>:8000/ping
```

## 📊 Scaling to Multiple RPis

**For RPi 2:**
- Set `RPI_ID=rpi_2`
- Set `API_PORT=8002`
- Use different IP: `192.168.1.102`

**For RPi 3:**
- Set `RPI_ID=rpi_3`
- Set `API_PORT=8003`
- Use different IP: `192.168.1.103`

## 🎯 Testing Production Setup

**Test 1: Hardware Detection**
- Expected: Automatically detects 1-12 Octoboards
- System adapts to available channels

**Test 2: IV Sweep**
- Start measurement from dashboard
- Verify files appear on Main PC
- Check Config.txt and Status files

**Test 3: Auto-recovery**
- Unplug network cable → Replug
- Should reconnect automatically
- Files should resume transferring

**Test 4: Scaling**
- Add more Octoboards
- Restart API server
- Should detect new boards automatically

## ✅ System is Production-Ready When:
1. API server starts on RPi boot
2. Boards detected automatically (any number 1-12)
3. Files transfer to Main PC successfully
4. Dashboard shows correct channel count
5. System recovers from network issues
6. Status files persist across restarts

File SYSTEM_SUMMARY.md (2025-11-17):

# OctoBoard System Summary

## ✅ System Configuration (Updated)

### Data Storage Location
**Main PC Storage Path:**
```
C:\Users\ManishJadhav\SynologyDrive\Rayleigh\Outdoor Data
```

### Folder Structure
```
Outdoor Data/
├── 1234/                          # Sample ID folder
│   ├── Config.txt                 # Measurement configuration
│   ├── a/                         # Pixel a data
│   │   ├── IV_2025-11-17_10-00-00.csv
│   │   ├── IV_2025-11-17_11-00-00.csv
│   │   └── ...
│   ├── b/                         # Pixel b data
│   │   └── IV_*.csv
│   ├── c/                         # Pixel c data
│   │   └── IV_*.csv
│   └── d/                         # Pixel d data
│       └── IV_*.csv
└── 5678/                          # Another sample
    ├── Config.txt
    ├── a/, b/, c/, d/
    └── ...
```

## 📋 Config.txt Format
Each sample folder contains a `Config.txt` file with measurement parameters:
```
Sample ID: 1234
RPI ID: rpi_1
Start Channel: 0
Channels Used: 0 to 3
Cell Area: 1.0 cm²
Current Limit: 50.0 mA
Start Voltage: -0.5 V
Stop Voltage: 1.2 V
Voltage Step: 0.01 V
Settle Time: 0.05 s
Measurement Type: iv_sweep
Started: 2025-11-17 10:00:00
IV Sweep Interval: Every 1 hour(s)
```

## 🔄 How It Works

### 1. Start a Measurement
- Go to dashboard: http://localhost:8501
- Navigate to "📝 New Measurement" tab
- Fill in Sample ID and IV parameters
- Select RPi and Slot (0-23)
- Click "Start Measurement"

### 2. What Happens Next
1. **Config.txt Created**: RPi creates `Config.txt` with all measurement parameters
2. **Initial IV Sweep**: RPi immediately performs first IV sweep for all 4 pixels (a, b, c, d)
3. **Data Transfer**: All files (Config.txt + 4 IV CSV files) are transferred to Main PC
4. **Hourly Repeats**: Every 1 hour, RPi automatically:
   - Performs IV sweep for all 4 pixels
   - Generates 4 new CSV files (one per pixel)
   - Transfers them to Main PC

### 3. File Naming
- **Config**: `Config.txt` (created once at start)
- **IV Data**: `IV_YYYY-MM-DD_HH-MM-SS.csv` (one per pixel per hour)

### 4. IV Data CSV Format
```csv
timestamp,voltage,current,power
2025-11-17T10:00:00,0.0,0.0,0.0
2025-11-17T10:00:01,0.1,0.001,0.0001
...
```

## 🖥️ System Architecture

### Components Running:
1. **Main PC Dashboard** (Streamlit)
   - URL: http://localhost:8501
   - Port: 8501
   - Purpose: Web UI for system control

2. **Main PC File Receiver** (FastAPI)
   - URL: http://localhost:8000
   - Port: 8000
   - Purpose: Receives files from RPis

3. **RPi 1 API Server** (FastAPI) - Currently Simulated
   - URL: http://localhost:8001
   - Port: 8001
   - Purpose: Controls 96 channels, performs measurements

### Network Configuration
**For Testing (Current Setup):**
- Dashboard: `localhost:8501`
- File Receiver: `localhost:8000`
- RPi 1-3: `localhost:8001-8003`

**For Production (Actual Hardware):**
- Main PC: `192.168.1.100`
- RPi 1: `192.168.1.101:8001`
- RPi 2: `192.168.1.102:8001`
- RPi 3: `192.168.1.103:8001`

## 📊 System Capacity

| Component | Specification |
|---|---|
| Total RPis | 3 |
| Channels per RPi | 96 (12 Octoboards × 8 channels) |
| Total Channels | 288 |
| Samples per RPi | 24 (1 sample = 4 pixels = 4 channels) |
| Total Samples | 72 |
| Pixels per Sample | 4 (a, b, c, d) |
| IV Sweep Interval | Every 1 hour |
| Files per Sample per Hour | 4 (one per pixel) |

## 🚀 Quick Start Commands

### Start Main PC Systems:
```powershell
# Terminal 1: Dashboard
cd main_pc_system
.\venv\Scripts\Activate.ps1
streamlit run dashboard.py

# Terminal 2: File Receiver
cd main_pc_system
.\venv\Scripts\Activate.ps1
python file_receiver.py
```

### Start RPi Systems (Simulated):
```powershell
# Terminal 3: RPi 1
cd rpi_system
.\venv\Scripts\Activate.ps1
$env:OCTOBOARD_SIMULATION="True"
python api_server.py
```

### Access Dashboard:
Open browser: http://localhost:8501

## ✅ Current Status

- [x] Data path changed to `C:/Users/ManishJadhav/SynologyDrive/Rayleigh/Outdoor Data`
- [x] Config.txt auto-generation implemented
- [x] Folder structure: `SampleID/a/`, `SampleID/b/`, `SampleID/c/`, `SampleID/d/`
- [x] Config.txt stored in sample root folder
- [x] Hourly IV sweep scheduler active
- [x] File transfer to Main PC implemented
- [x] Dashboard connected to RPi 1 (simulated)
- [ ] File receiver not yet started
- [ ] Test complete measurement workflow
- [ ] Verify hourly automation

## 🔧 Next Steps

1. **Start File Receiver**: Run `file_receiver.py` on Main PC
2. **Start Test Measurement**: Use dashboard to configure and start a sample
3. **Verify Files**: Check that Config.txt and IV files appear in SynologyDrive folder
4. **Test Hourly Sweep**: Wait or modify interval to test automation
5. **Visualize Data**: Use "Data Visualization" tab to plot IV curves

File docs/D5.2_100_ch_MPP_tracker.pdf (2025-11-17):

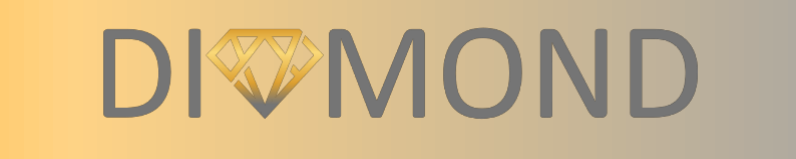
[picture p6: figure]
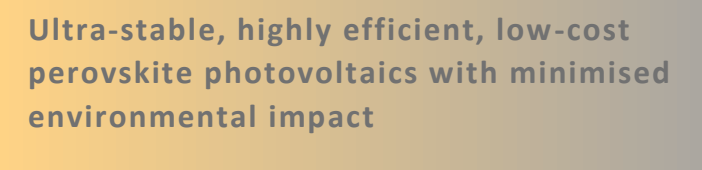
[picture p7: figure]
perovskite photovoltaics with minimised environmental impact

Ultra-stable, highly efficient, low-cost

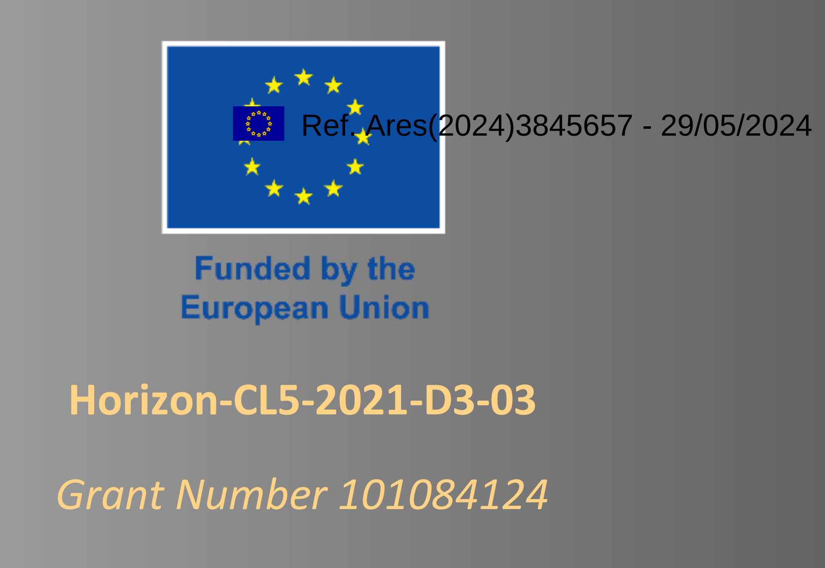
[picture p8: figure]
Horizon-CL5-2021-D3-03; Grant Number 101084124; Ref. Ares(2024)3845657 - 29/05/2024

# Deliverable D5.2 – Report on the first operation of novel developed maximum power point tracker (MPPT) with 100 channels

No. | Participant organisation name | Type | Country
1 (Coord) | FhG | Fraunhofer-Institut für Solare Energiesysteme ISE | RTO | DE
2 | DYE | Dyenamo AB | SME | SE
3 | UG | Rijksuniversiteit Groningen | UNI | NL
4 | BeD | BeDimensional | SME | IT
5 | UU | Uppsala Universitet | UNI | SE
6 | EPFL | École Polytechnique Fédérale de Lausanne | UNI | CH
7 | UTV | Università degli Studi di Roma Tor Vergata | UNI | IT
8 | SNX | Solaronix SA | SME | CH
9 | UP | Universidade do Porto | UNI | PT
10 | PIX | Pixel Voltaic Lda | SME | PT
11 | UM | Philipps-Universität Marburg | UNI | DE
12 | CEA | Commissariat à l'Énergie Atomique et aux Énergies Alternatives | RTO | FR
Start date of the project: 01/12/2022 Duration of the project: 36 months | Project Coordinator: Uli Würfel Institution of the Coordinator: FhG
Deliverable No. | D5.2 | Lead Beneficiary: | UM
Period covered by the report: | from 01/12/2022 to 31/05/2023
Type: | R | Dissemination Level: | PU
Due date (month): | 18 | Work Package No.: | WP5
No. pages: | 17

History of changes

Version

V1.2 – Final

Version

Date | 29/05/24

HORIZON-CL5-2021-D3-03
Stable high-performance Perovskite Photovoltaics

## Table of Contents

## 1. Executive Summary

This report presents the development, functionality, and operation of a newly developed maximum power point tracker (MPPT) equipped with over 100 channels for simultaneous maximum power point (MPP) operation. This system is an important tool in WP 5, which focuses on the stability assessment of the perovskite solar cells. The MPPT system, consisting of custom-developed printed circuit boards and associated software, enables extensive aging and degradation studies under real-world stress conditions.

The system was realized and tested by ageing >100 perovskite solar cells for >100 h under simulated sunlight. By optimizing the choice of electronic component, the system could be realized at a cost below 10€ per channel, i.e., per measured solar cell.

Moreover, the protocol for outdoor ageing in T5.4 is defined in this report.

## 2. Introduction

The Diamond project has been established to address the critical challenges of stability and efficiency in perovskite solar cells. The focus on improving the longevity and performance of these cells through material innovation and advanced testing methodologies is crucial for their eventual market viability.

Within this context, WP 5 is dedicated to the stability assessment of perovskite solar cells. One shortcoming previously identified has been the lack of statistically significant data when it comes to ageing of perovskite solar cells. To overcome this problem, the deliverable D5.2 focuses on the development and deployment of a cost-effective maximum power point tracker (MPPT) system capable of MPP tracking over 100 channels, i.e., 100 solar cells, simultaneously. This system is instrumental in conducting large-scale, statistically significant aging studies under predefined stress conditions that mimic real-world environmental impacts as well as for large scale outdoor aging campaigns.

The hardware developed for this task includes the development of printed circuit boards (PCBs) with the capability to perform Source Measure Unit (SMUs) functions on eight cells at once. These are complemented by specially designed chucks that ensure compatibility with the cell layouts used in the Diamond project. The choice of hardware enabled a low-cost realization at a price of <10€/channel.

The software component enables the functionality of this setup, allowing scalable control through an I2C interface from low-cost devices such as Raspberry Pis or other single board computers (SBCs).

## 3. Design of Measurement Electronics

A source measure unit consists of a Digital-to-Analog Converter (DAC) to apply voltage and source current to the Device-under-Test (DUT) and an Analog-to-Digital Converter (ADC) to measure voltage and current flowing through the DUT with sufficient accuracy. Each here described MPP-channel consists of a DAC, ADC and a DUT.

The tailoring of the requirements is crucial to reduce cost per channel in the system, targeting costs of 10€/channel. The key reduction of requirements are as follows:

- Limit of the voltage to range between 0 and 5 V: This is in the voltage range for most commercial ICs required for the device. On the other hand, single-junction solar cells practically never exceed 2V in open-circuit voltage. This voltage range is a sweet-spot to directly interface with off-the shelve integrated circuits (ICs) while also covering the voltage range of typical single junction up to potentially triple-junction tandem devices.
- Limit of the source/sink current to a range from 100 µA to 50 mA: The order of magnitude of the current required to characterize solar cells is primarily a function of the irradiance and cell area. Typical laboratory scale perovskite solar cells have an active area in the range from 0.1 mm² to 1 cm² . For the relevant irradiance of AM1.5 G this results in a current between 2 mA and 40mA (allowing for variations in the bandgap). The high end of the range is limited by the current source and sink capability of the setup, the lower range is limited by the measurement accuracy when using a shunt resistor for current measurement, parasitic leakage current through the analog multiplexers and the limited input impedance in the ADC during the conversion process.
- Limit data rate to below 1 sample-per-seconds (SPS): For practical application the stability of solar cells must be in the range of multiple years. Under constant illumination the data rate can be limited compared to typical current-voltage measurements which require multiple datapoints per second for fast measurements of the current-voltage-curve (JV-Curve) of a solar cell.

While reduction in cost is one challenge, the other challenge is scaling of the system. For the DUT to remain under the desired operating conditions (maximum power point), each channel must have at least one DAC so that voltages can be continuously and individually applied to each DUT, while the data acquisition can be multiplexed. This shows that control of the of the DACs is the limiting factor when it comes to scalability of the system, and the choice of this component is crucial in meeting the goal of the deliverable.

Between the market availability of the ICs, the cost of the ICs, the available software for interfacing with the ICs and the ability to scale, the MCP4728 from Microchip Technologies was chosen for this task. Each device has 4 individually controllable integrated DACs and the I2C address of each device can be changed to one out of 8 possible addresses. This allows to control up to 8 devices on a single I2C bus, providing 32 controllable outputs on a single I2C bus. This IC however does not have sufficient current handling capability for the requirement of ± 50 mA, therefor the output is buffered by the LMV234 from Onsemi, a unity-gain stable rail-to-rail quad operational amplifier.

From a cost perspective the DACs and ADCs are some of the most expensive items on the Bill of Materials (BOM). While the number of DACs cannot be reduced, due to the requirement of individual control, the ADCs input can be multiplexed to measure several DUTs sequentially. From a software and hardware availability perspective the ADS1115 from Texas Instruments was chosen as the ADC. The 4 available inputs and the extensive multiplexing setup capabilities also enables the system to perform 4-wire measurements. Two inputs are used for the current measurement through a measurement resistor and two inputs can be configured to measure the voltage at the DUT. The ADS1115 is also controlled through the I2C interface and can be configured to one of four addresses.

The ADC frontend multiplexing setup is realized through the 74HC4051 8-channel analog multiplexer/demultiplexer from Nexperia. One of the key characteristics is the low leakage current below 1 µA of each channel. This leakage is one fundamental factor limiting the low end of the current range and measurement accuracy.

Controlling the 8 states of the analog multiplexer requires three input pins, while these could be controlled from the main SBC, this would require more available pins and limits scaling. Thus, an I/O-Expander is used to control these pins via the I2C interface. Four of the remaining pins on the I/O-Expander are used as inputs to a voltage divider. The output from the voltage divider is buffered through the same operational amplifier LMV234 from Onsemi to provide a common ground for the DUTs that is neither 0V (Ground) or 5 V (VDD). This allows for cells of different polarity to be measured simultaneously and it can be used to measure IV-curves under reverse bias conditions, which can be scientifically relevant.

In the initial stages of the design, the scalability aspect was still not fully solved and two solutions were pursued. Many Single-Board-Computer (SBC) planned to control the devices on the I2C bus only expose a single I2C bus, thus necessitating multiple SBCs to scale efficiently, which then would have to be controlled on a network level (TCP/IP). The alternative solution considered was to use microcontroller boards with USB-connections, specifically the Raspberry Pi Pico (Pico Pi) to perform the multiplexing on the USB-Level, using of-the-shelve USB-hubs. Thus, the board was designed with the capability to plug in a Pico Pi directly on top, with a pin compatible header. This would have also allowed to compensate for problems with the I/O-Expander as each controlled pin is also exposed to the Pico Pi. While the solution featuring a Pico Pi has been proven unnecessary, the final design still features this connection. This would still enable this potential solution in case one wants to effectively control a single board, directly from a Personal Computer via USB through a Pico Pi.

The final board layout of the measurement electronics unit is depicted in Figure 2, top. As each board can address eight channels, for simplification these will be referred to as “octoboards” in the following.

Figure 1, bottom, shows the topology of the complete MPPT system:
- The system is controlled by a single board computer (Raspberry Pi 4B).
- Over four I2C busses, four bundles of 3-4 octoboards, each, are addressed by four parallel running python scripts.
- These electrical components can all be powered by a single power supply.
- Each octoboard is connected to one measurement-chuck unit (cf. Figure 2), allowing to contacts a total of eight solar cells.
- All substrates are mounted on a single sample holder plate which is placed inside a solar simulator.

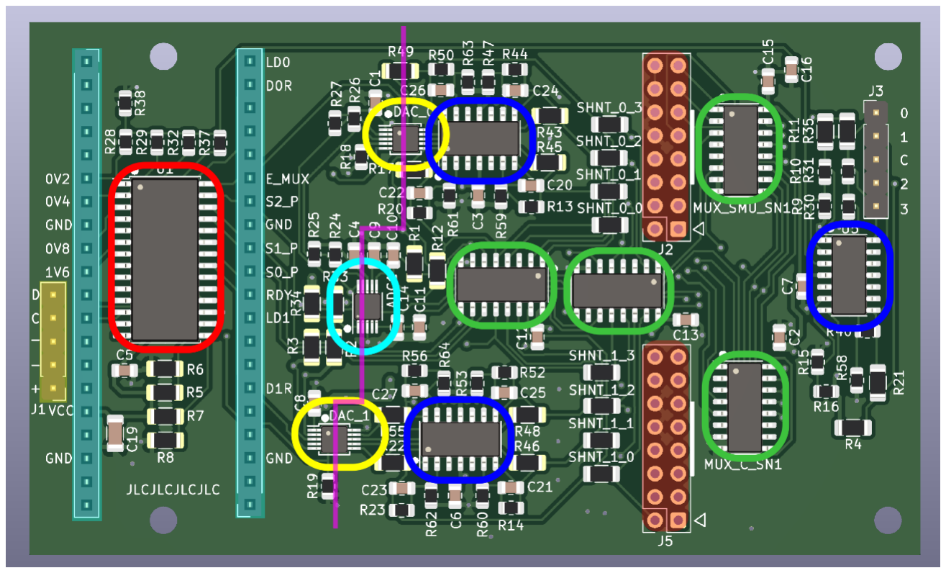
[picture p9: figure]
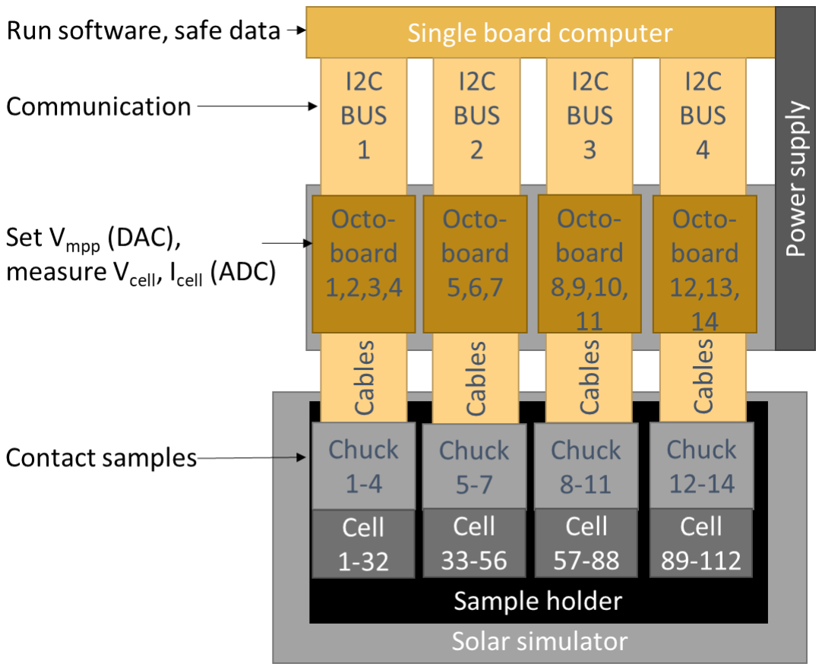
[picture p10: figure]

Figure 1: Top: Final layout of a single eight-channel SMU. The 1x05 header for connection to an SBC is highlighted in yellow. Two 1x20 headers for connecting to a Pico Pi are highlighted in turquoise. The two 2x08 headers for connection to the DUTs are highlighted in orange. The I/O expander and analog multiplexers are circled in red and green, respectively, operational amplifiers in blue, the ADC in turquoise, and the two DACs in yellow. The magenta line separates the digital and the analog part of the board.
Bottom: Topology of the MPPT system comprising the single board computer, octoboards and sample holder with mounted solar cells.

## 4. Construction of Sample Holder

To efficiently mount cells as DUTs a sample holder had also been developed. The holder consists of sample holder units that can provide the electrical connection of two substrates to the corresponding eight channel SMU octoboards via pogo-pins (cf. Figure 2). The holders are designed for the solar cell layout that has been agreed upon by the DIAMOND partners for ageing test, wherein four solar cells are embedded onto one 25x25mm² glass.

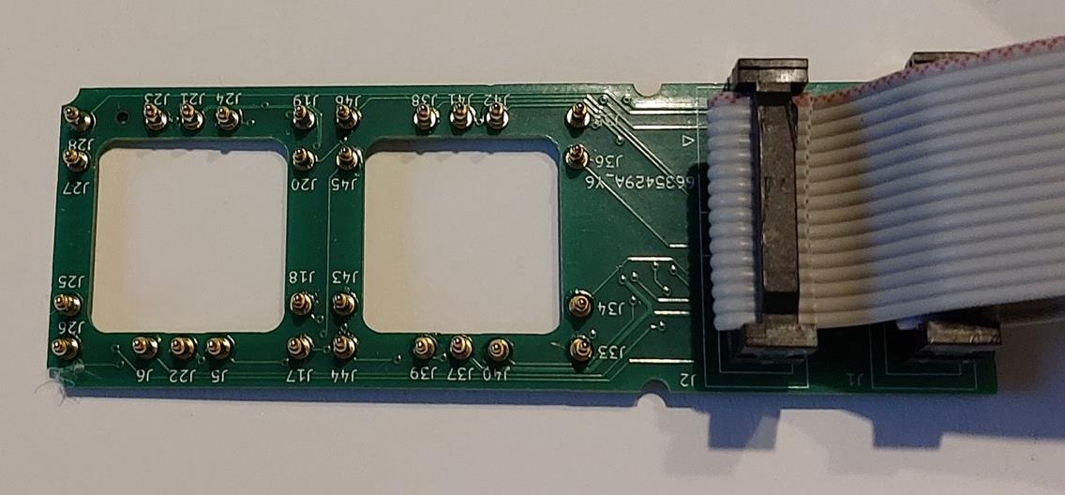
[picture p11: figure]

Figure 2: Sample holder unit are designed for a minimal unit of two substrates to provide contact between the solar cells and the SMU boards. Two 2x08 headers on the right are used for connection to a single eight-channel SMU. Pogo pins on the left provide connecting two substrates. The hole in the PCB also allows for thermal connection of the substrates to a cooling unit.

Figure 3 shows the design of the complete sample holder. The sample holder can hold to 28 substrates, i.e., 112 solar cells. Four to six substrates each can be individually mounted by pressing the samples onto the pogo-pins with a screw-mountable cover plate to provide electrical contact. The sample holder has a solid metal base plate with thermal connection to the substrates to allow good thermal coupling. This plate can be placed onto a thermally controlled chuck to enable active cooling. Electrical connection to the octoboards is provided via multipoint connectors. The frame between the samples (green in the CAD drawing of Figure 3) is made from electrically isolating PET to prevent shunting of the samples. The top side of the holder was designed to allow for optimal illumination of the sample while unwanted back reflection into the solar simulator is minimized. The plate can be placed under a solar simulator ageing station for indoor illumination or as well as outdoors.

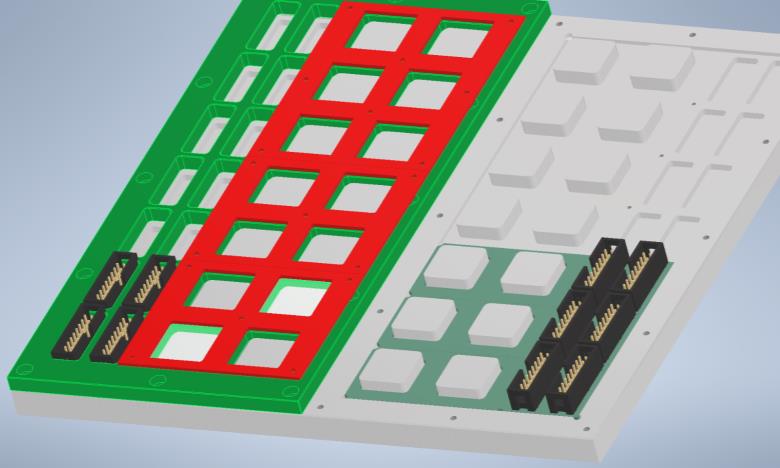
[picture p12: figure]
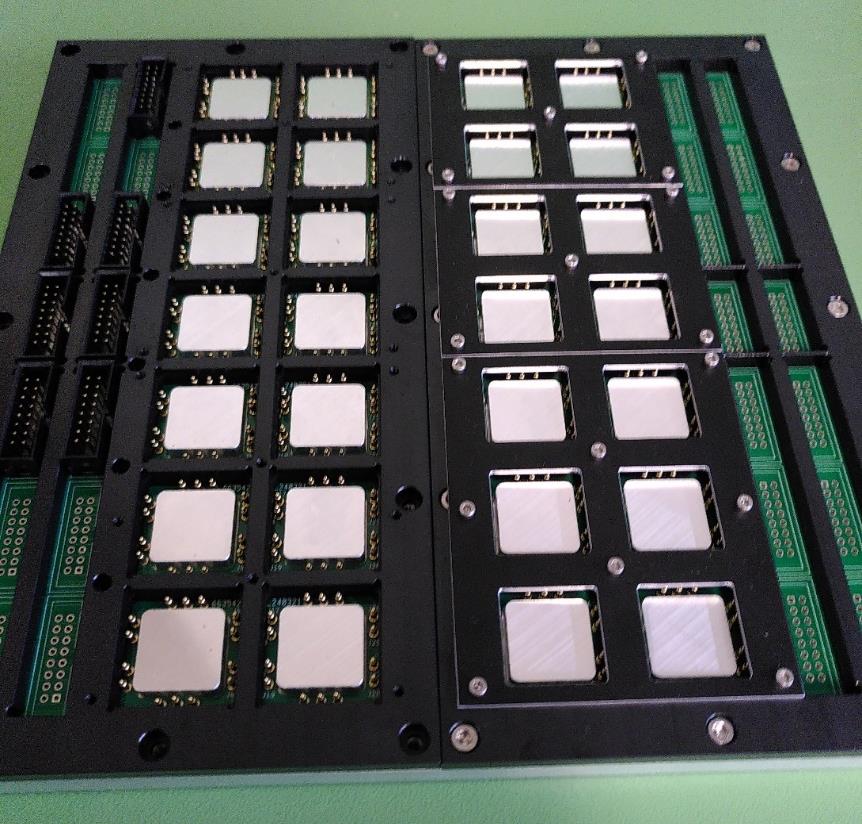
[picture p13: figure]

Figure 3: Solar cell holder. Top: CAD drawing of the setup. 14 solar cells substrates of 4 cells each can be placed on the holder. Grey shows the metal baseplate that acts as a heatsink. The sample frame made of electrically non-conducting PET is shown in green. Samples are pressed onto the pogo-pins (not displayed here) with the front-plate displayed in red. This plate is designed for fast and flexible (de-) mounting of groups of 2 substrates. Electrical connection is provided by the multipoint connectors (black/ gold).
Bottom: Photograph of the corresponding sample holder The photo shows the sample holder in a pre-finalized state to provider a better understanding of the assembly.

## 5. Software Design and Implementation of Data Logging

The software controlling the MPP tracker utilizes a Python-based system operated from a Raspberry Pi. The Raspberry Pi is also used for data logging and storage. This setup employs the Raspberry Pi’s I2C interface to communicate with 4 octoboards on one I2C channel. The script has an Initialisation Process and an Operational Loop within which the MPP Algorithm is operated.

Initialisation Process:
The software begins by incrementally adjusting the common voltage and each individual DAC output to establish a stable common voltage level at around 2.5V. This careful adjustment is crucial to prevent any significant reverse biasing of the cells, yet the voltage allows MPP tracking irrespective of the individual cells’ polarity. During this phase, the software also runs a preliminary operational loop for each channel, where it measures the short-circuit current (Isc) at 0 V. If Isc exceeds a predetermined threshold (Ithresh), the software methodically adjusts the voltage to find a good initial approximation of the maximum power point voltage (Vmpp) and current (Impp) for each cell, the sign of the inital Isc is also used to determine the polarity of the cell at each respective channel. This part of the process is essential for setting a baseline for more precise power optimization in subsequent steps. If the short-circuit current is below the threshold, the channel is considered not to be connected and is excluded from the operational loop.

Operational Loop and Data Logging:
After the initial setting of Vmpp, the software enters the main operational loop, where the iterative MPP algorithm is executed. This algorithm operates through five steps on each channel where the initial Isc was greater than the threshold. The final values are stored on the disk. This loop continues across all available channels, repeating indefinitely until the script is manually stopped. The key data points, time, voltage, and current are logged and saved to a CSV file. This file is systematically named using a convention that includes the I2C pins used, the I2C address offset of the specific SMU-Board (ranging from 1 to 4), and the channel number on the SMU-Board (ranging from 1 to 8). This approach to data management ensures that the recorded information is well-organized and easily retrievable for analysis, without the need to manually input parameters beforehand. With a simple CSV file as interface, it also allows for network-based storage or periodic cloud upload as a backup for the measured data.

MPPT algorithm:
The algorithm optimizes the voltage applied to the solar cell in each channel to maximize the power output. It starts by measuring the voltage (Vcell) and current (Icell) from the solar cell to calculate its power output. This data is appended to the file corresponding to this specific channel. The power is then compared with that from the previous measurement. If the measured power after the last voltage adjustment has increased, the algorithm slightly increases the voltage adjustment step, continuing the adjustment of the applied voltage in the same direction to enhance power output further. If the power decreases or remains the same, the algorithm reduces the adjustment step and reverses the voltage adjustment direction, to allow for the possibility that the maximum power point is at a slightly lower voltage setting. The reduction of the voltage step is crucial to eventually modulate the applied voltage only a minimal amount around a potentially stable maximum power point. The increase of the voltage steps in case the direction of voltage adjustment increases in delivered power by the solar cells allows for faster following of quick changes in the maximum power point. This process of adjusting, measuring, and refining continues is performed consecutively on each channel of the whole device.

## 5. Implementation and Testing

All PCBs have been designed with KiCad and manufactured by a commercial PCB manufacturer. Soldering of specific connectors and final cabling was carried out at University of Marburg. The cable management was optimized for ease of handling of the system for users while not compromising signal quality over the I2C data lines as well as measurement lines. The entire measurement electronics was stored in a custom-made housing unit that enables efficient handling and maintenance.

A demonstrator was designed for 14 octoboards, i.e., the system can measure 112 solar cells and has 112 channels. While this is a practicable size for a first MPPT system, our design is modular and easily scalable to larger numbers of channels.

Figure 4 shows the complete MPPT system. On the left, the 14 octoboards controlled by the Raspberry Pi single board computer are displayed. As shown on the right, these boards are connected to the 112 solar cells, mounted on the sample holder and placed inside the solar simulator ageing station.

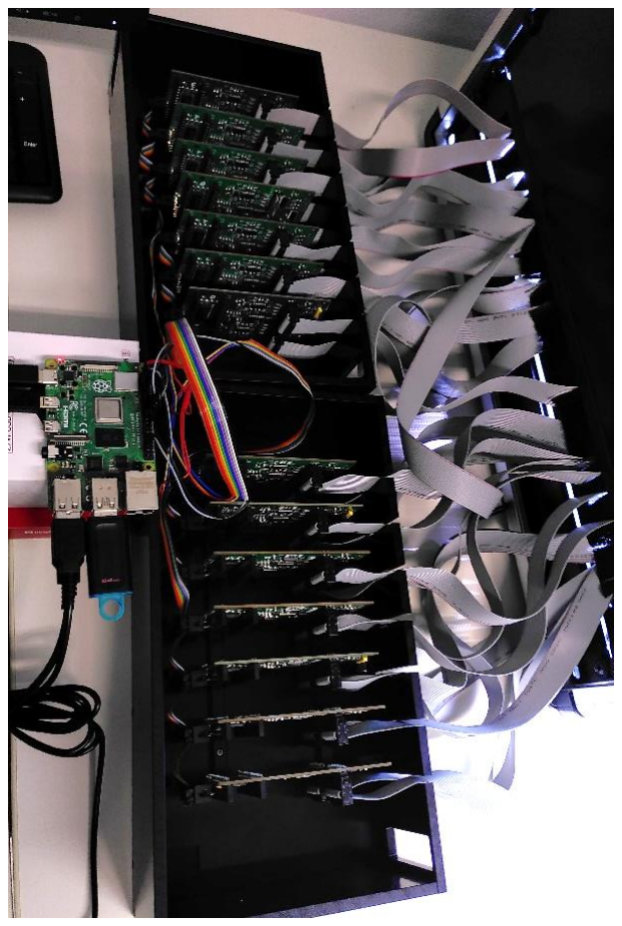
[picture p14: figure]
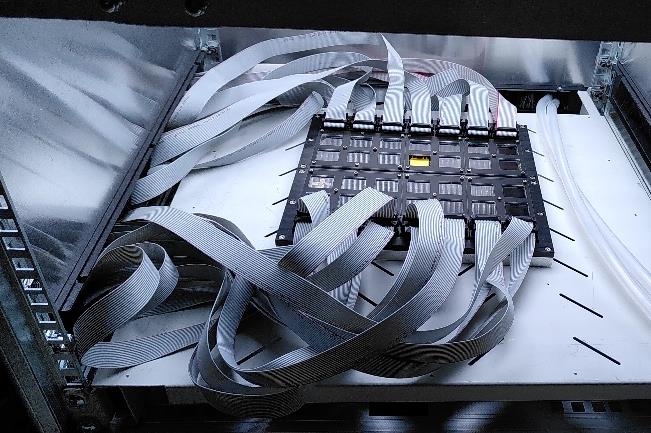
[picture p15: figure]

Figure 4: Photograph of the high throughput MPP tracking system that allows simultaneous MPP tracking of 112 solar cells. Left: array of 28 printed circuit boards comprising of the measurement electronics. All boards are controlled by a Raspberry Pi single board computer. Right: Sample holder to contact and hold 28 substrates comprising of a total of 112 solar cells. The sample holder is placed inside a class A solar simulator ageing station.

Figure 5 demonstrates the successful proof of concept: MPP tracking of perovskite solar cells under simulated solar light (Class A AM1.5g ageing station) has been demonstrated for >100 channels over >100 h.

Interpretation of the measured data: As one can see, the power at MPP of most devices degraded significantly within the first 20 h of measurement. We ascribe this to the fact that the samples were not encapsulated and hence exposed to air during the measurement, which is known to cause rapid degradation in most perovskite solar cells. Due to manufacturing issues in this batch of >100 solar cells, the power conversion efficiency of some samples was very low. Such low power samples are challenging to the system, but one can see that the MPPT system can also handles these cases. Some curves display a noisy signal, which is probably due to a high contact resistance between the tip of the pogo pins and the solar cell contact pads. In the following experiments, we will try to mitigate this by adding silver conductive paint to the samples to improve the contact resistance.

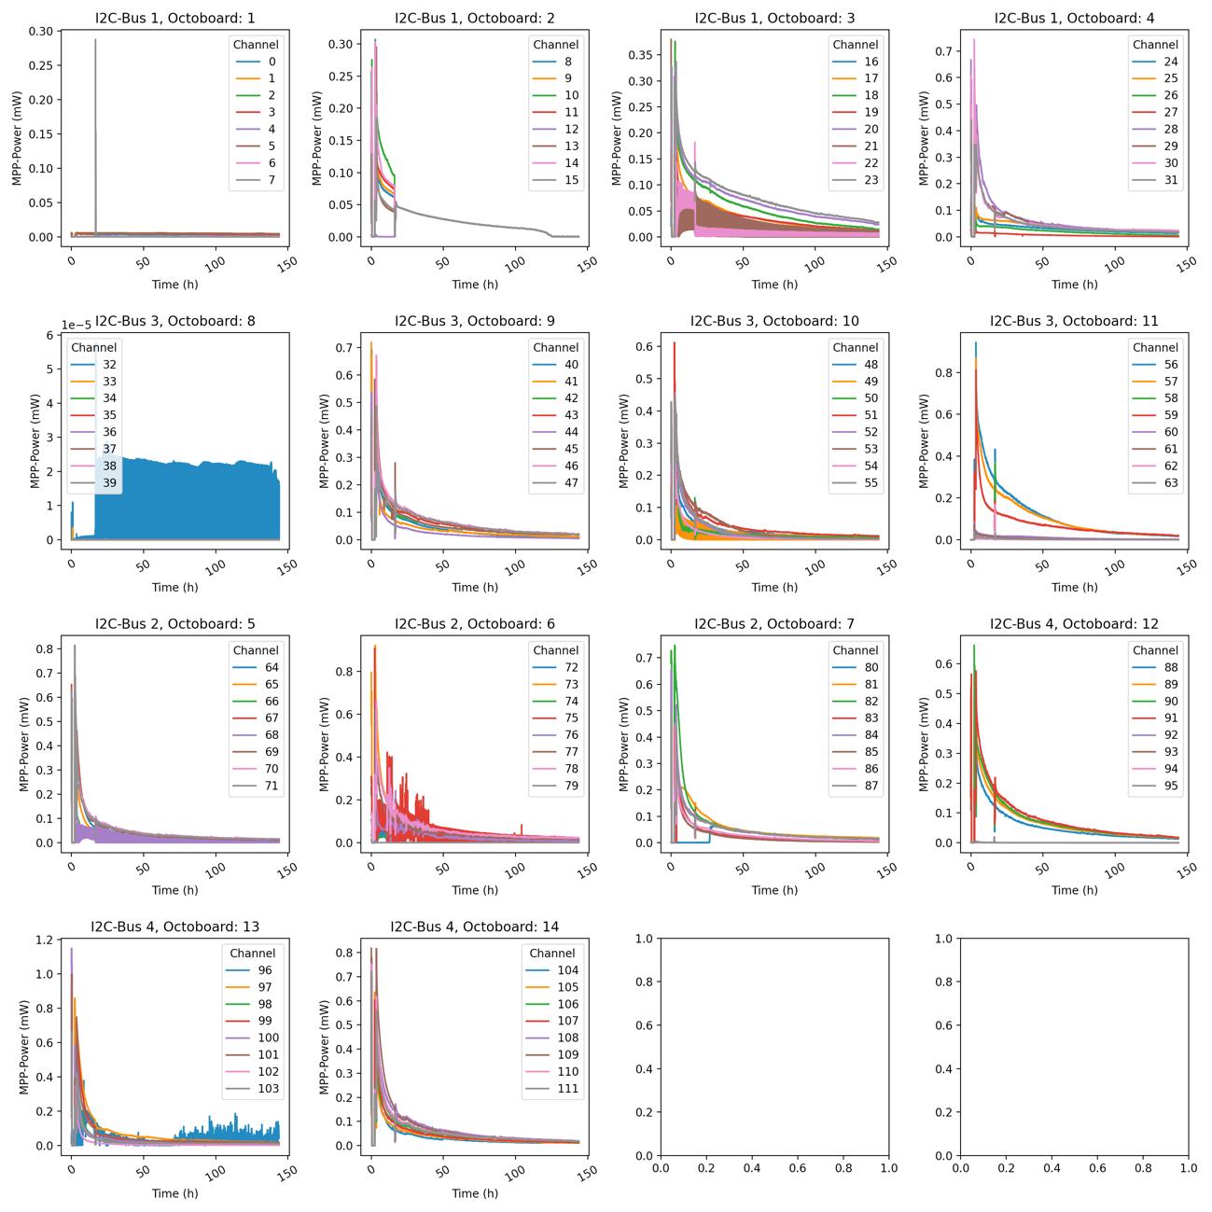
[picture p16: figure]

Figure 5: Measured maximum power point values of 111 solar cells tracked with the MPPT system for > 100 h.

## 7. Cost analysis

A key requirement of the low-cost laboratory MPP-tracker system is the comparatively very low cost per measurement channel, targeting a price as low as 10 €/channel.

The core technological component of the system is represented by the measurement electronics and computation units. By carefully designing the measurement electronics to fulfil the complete parameter space required for measuring laboratory type solar cells while on the other hand not unnecessarily overdesigning the measurement range, the price for electronic components could be significantly reduced. Likewise, for computational units, Raspberry Pi components offer a powerful and cost-efficient solution.

Besides the pure cost of hardware components, integration of electronics on a PCB represents a significant cost driver. German PCB-manufacturers have been considered but the cost estimate was about five times higher than the services from the Chinese manufacturer JLCPCB, which was finally chosen to assemble the parts.

In the following table and in Figure 6, the costs for the demonstrator system described in this report are listed. The cost of all electronic components adds up to 4.31 €/channel. One can clearly see that the octoboards account for approximately half of the cost, which is justified since this unit was custom designed and comprises many electronic components. It represents the core of the MPPT setup where all the measurement is carried out. The sample holders account for the second largest share of cost. This is especially due to the fact that the assembly of pogo-pins is associated with additional costs in PCB manufacturing due to their high aspect ratio. The other components, Raspberry Pi 4B, power supply, level shifter, and cables & connectors account in sum for less than ¼ of the cost.

Component | Quantity used | Per piece price [EUR] | Price per channel [EUR]
Octoboards | 4 | 27.1 | 2.15
Sample holder unit | 4 | | 1.22
Raspberry Pi 4B | 1 | 40.51 | 0.32
Power supply | 1 | 10.51 | 0.08
Level shifter | 4 | 1.45 | 0.05
Unit of cables & connectors | 16 | 3.98 | 0.50
Total | | | 4.31
All components cost include shipping, taxes and customs

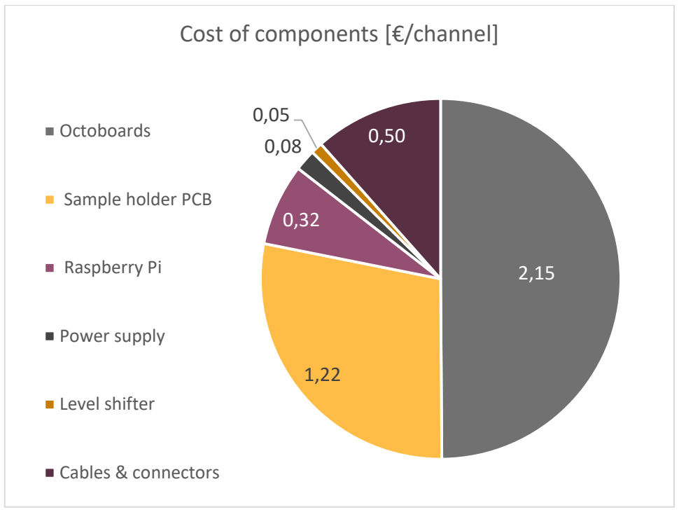
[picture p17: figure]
Cost of components [€/channel]; Octoboards; Sample holder PCB; Raspberry Pi; Power supply; Level shifter; Cables & connectors

Figure 6. Proportionate cost of the price of each component of the MPPT system. The total cost is 4.31 €/channel.

It needs to be noted, that the material and manufacturing (tooling costs) for the mechanical parts of the sample holder and the box to hold the octoboards amounted to 1,511 EUR, i.e. 11.81 EUR/ channel. This design was not optimized for minimal cost and if costs need to be optimized, then a significantly cheaper sample holder can be constructed. Yet, such a cheaper holder may not be thermally coupled to a cooled chuck. In the above calculation, the personnel costs for the assembly of the cables and connecters were also not included. This process required several iterations and we are therefore not able to provide an accurate estimate of the required assembly time.

Overall, the assessment shows that the core component, namely the measurement and processing units, can be manufactured at very low costs well below 10 EUR per channel in a modular way that allows for straight forward scaling of the system. These components are universally deployable virtually in any laboratory environment. Peripherical components like the sample holder need to be individually adjusted to the specific laboratory or outdoor environment where the MPPT system is to be installed.

## 8. Definition of outdoor ageing conditions

As agreed in the grant agreement, in this deliverable report, the conditions for outdoor ageing in various partner laboratories within WP5 are also specified in D5.2 as follows:

Partner | UP | UU | SNX | FhG | CEA
Light source | Natural sunlight | Natural sunlight | Natural sunlight | Natural sunlight | Natural sunlight
Electrical load: | Open circuit Option of MPP tracking for one channel. | Open circuit, short circuit and MPP tracking are possible. | Open circuit. Option of MPP tracking for two channels. | MPP or open circuit | MPP or open circuit
Sample type (cell or module) | For simulated light up to 12x12 cm2, for natural light no limit. | Both cell or module. | Up to 20x20 cm (1 sample). | Small cell and module (µW to 25 W, 0-50V µA up to 1 A) | Both cell or module.
Periodic I-V measurements | Outdoor measurement for one module/panel. | Possible for natural light. Additional measurements can be added under simulated sunlight. | Possible for natural light. Additional measurements can be added under simulated sunlight. | Possible for natural light. Additional measurements can be added under simulated sunlight. | Possible for natural light. Additional measurements can be added under simulated sunlight.
Peripherical measurements: | Irradiance, temperature and humidity. | Irradiance and temperature. | Irradiance and temperature. | Irradiance and temperature. | Irradiance and temperature.
Orientation of the samples | Flexible adjustment of orientation and angle for optimal orientation. | True south, 42° elevation, can be adjusted with special fixtures. | South facing, optimal angle. | South-facing and fixed at the optimal angle (32°). | South-facing and at optimal angle.
Encapsulation | Small cells can be tested in air tight box (maximum illumination area of 15x15 cm2). | Encapsulation is needed. If an air-tight box is provided, it can be also mounted. | Encapsulation is needed. SNX can also build a transparent air tight box customized to desired sample sizes. | Samples have to be encapsulated, no air tight box available | Samples have to be encapsulated.

## 9. Conclusion

For this deliverable, an MPPT system was successfully designed, implemented, and tested, at a cost well below the already ambitiously targeted aim of 10 € per channel.

This was facilitated by the design and manufacturing of measurement electronics and sample holder. Software and corresponding data logging technologies have been successfully developed. The viability of the system was successfully tested by measuring >100 perovskite solar cells in the MPPT for a time >100 h.

This is an essential step forward for the goals of the DIAMOND project. In the next months, the system will be used to acquire statistically relevant ageing data of a larger numbers of solar cells.

Disclaimer excluding Agency responsibility

Funded by the European Union. Views and opinions expressed are however those of the author(s) only and do not necessarily reflect those of the European Union or Horizon 2.5. Climate, Energy and Mobility programme under Grant Agreement No. 101084124. Neither the European Union nor the granting authority can be held responsible for them.

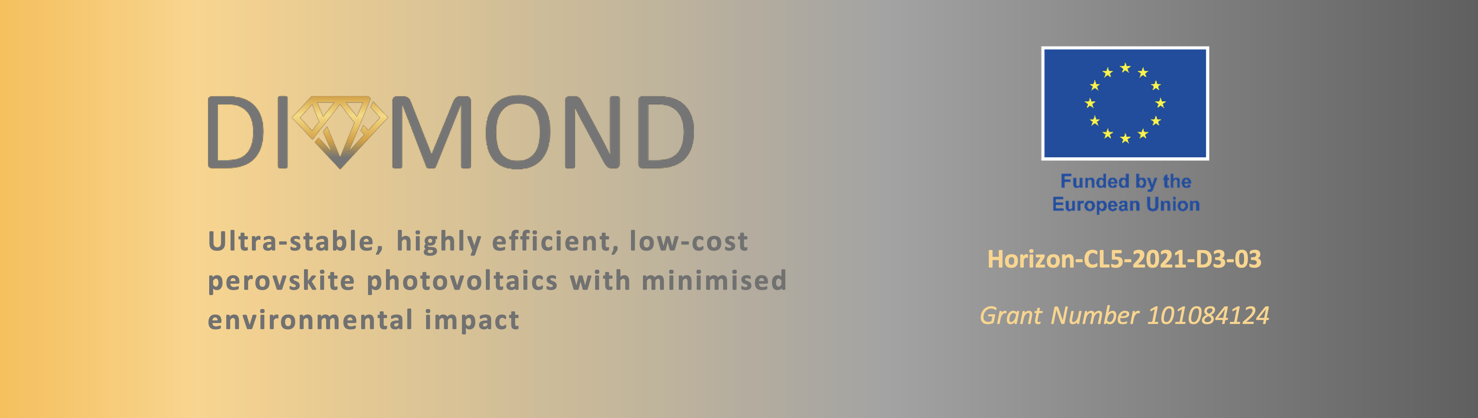
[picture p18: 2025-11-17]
docs/images/diamond_header.png

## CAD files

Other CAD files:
hardware/Measurement Chuck Housing CAD Design/Assembly.iam
hardware/Measurement Chuck Housing CAD Design/Bauteil4.ipt
hardware/Measurement Chuck Housing CAD Design/Bauteil5.ipt
hardware/Measurement Chuck Housing CAD Design/Bauteil6.ipt
hardware/Measurement Chuck Housing CAD Design/DIN EN ISO 2338 - 3 h8 x 16.ipt
hardware/Measurement Chuck Housing CAD Design/DIN EN ISO 4762 - M2 x 3.ipt
hardware/Measurement Chuck Housing CAD Design/DIN EN ISO 4762 - M3 x 10.ipt
hardware/Measurement Chuck Housing CAD Design/DIN EN ISO 4762 - M3 x 20.ipt
hardware/Measurement Chuck Housing CAD Design/DIN EN ISO 4762 - M3 x 5.ipt
hardware/Measurement Chuck Housing CAD Design/DIN EN ISO 7046-2 Z - M2.5x10 - 8.8 - Z1.ipt
hardware/Measurement Chuck Housing CAD Design/Glasscheibe.ipt
hardware/Measurement Chuck Housing CAD Design/Glassubstrat_25x25x2,2.ipt
hardware/Measurement Chuck Housing CAD Design/Maske.ipt
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

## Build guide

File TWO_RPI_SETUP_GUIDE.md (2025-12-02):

================================================================================
                    TWO RASPBERRY PI SETUP GUIDE
                    Complete Step-by-Step Instructions
================================================================================

HARDWARE YOU HAVE:
- 2× Raspberry Pi (192.168.2.10 and 192.168.2.11)
- 1× TP-Link 5-Port Gigabit Switch
- 3× Ethernet cables
- 1× Windows PC
- Octoboards (to be connected to RPis)
- PuTTY and WinSCP installed on Windows

================================================================================
PART 1: PHYSICAL CONNECTIONS
================================================================================

Step 1: Connect Everything
---------------------------

1. Plug TP-Link Switch into power outlet

2. Connect Ethernet cables:
   - Cable 1: Windows PC → Switch (any port)
             (Use USB-to-Ethernet adapter if PC has no Ethernet port)
   - Cable 2: RPi 1 → Switch (any port)
   - Cable 3: RPi 2 → Switch (any port)

3. Power on both Raspberry Pis

4. Wait 1 minute for RPis to boot

================================================================================
PART 2: WINDOWS PC NETWORK CONFIGURATION
================================================================================

Step 2: Set Static IP on Windows
---------------------------------

1. Press Windows Key + R
2. Type: ncpa.cpl
3. Press Enter

4. Find your Ethernet adapter (might be called "Ethernet" or "Local Area Connection")
   - If using USB-to-Ethernet, look for new adapter that appeared

5. Right-click the adapter → Properties

6. Double-click "Internet Protocol Version 4 (TCP/IPv4)"

7. Select "Use the following IP address"
   - IP address: 192.168.2.1
   - Subnet mask: 255.255.255.0
   - Default gateway: (leave blank)
   - DNS servers: (leave blank)

8. Click OK → OK

9. Close Network Connections window

Step 3: Verify Windows IP
--------------------------

Open PowerShell and run:
```powershell
ipconfig
```

You should see:
```
Ethernet adapter Ethernet:
   IPv4 Address: 192.168.2.1
   Subnet Mask: 255.255.255.0
```

================================================================================
PART 3: RASPBERRY PI 1 SETUP (192.168.2.10)
================================================================================

Step 4: Connect to RPi 1 via PuTTY
-----------------------------------

1. Open PuTTY

2. Enter:
   - Host Name: 192.168.2.10
   - Port: 22
   - Connection type: SSH

3. Click "Open"

4. Login:
   - Username: pi
   - Password: raspberry (or your password)

Step 5: Transfer Files to RPi 1 via WinSCP
-------------------------------------------

1. Open WinSCP

2. New Session:
   - File protocol: SFTP
   - Host name: 192.168.2.10
   - Port number: 22
   - User name: pi
   - Password: raspberry (or your password)

3. Click "Login"

4. In WinSCP:
   - Left panel (Windows): Navigate to C:\Users\ManishJadhav\OctoBoard\rpi_system
   - Right panel (RPi): Navigate to /home/pi/
   
5. Drag the entire "rpi_system" folder from left to right

6. Wait for transfer to complete (may take 2-5 minutes)

7. Keep WinSCP open for later

Step 6: Configure RPi 1 (in PuTTY)
-----------------------------------

Run these commands one by one:

```bash
# Navigate to project
cd ~/rpi_system

# Verify start_rpi.sh configuration
cat start_rpi.sh | grep "export RPI_ID"
cat start_rpi.sh | grep "export MAIN_PC_IP"
cat start_rpi.sh | grep "export API_PORT"
```

You should see:
```
export RPI_ID="${RPI_ID:-rpi_1}"
export MAIN_PC_IP="${MAIN_PC_IP:-192.168.2.1}"
export API_PORT="${API_PORT:-8001}"
```

If correct, continue:

```bash
# Make start script executable
chmod +x start_rpi.sh

# Create virtual environment
python3 -m venv venv

# Activate virtual environment
source venv/bin/activate

# You should see (venv) in your prompt now

# Install Python packages (this takes 10-15 minutes)
pip install numpy>=1.22 fastapi>=0.104.0 uvicorn>=0.24.0 pydantic>=2.0.0 requests>=2.31.0 schedule>=1.2.0 adafruit-blinka>=7.3.3 adafruit-circuitpython-mcp4728>=1.0.8 adafruit-circuitpython-ads1x15>=2.3.9 adafruit-circuitpython-mcp230xx>=1.0.10
```

Wait for installation to complete...

```bash
# Enable I2C interface
sudo raspi-config
```

In raspi-config menu:
- Use arrow keys to navigate
- Select: "3 Interface Options"
- Select: "I5 I2C"
- Select: "Yes" to enable
- Select: "Ok"
- Select: "Finish"
- Select: "Yes" to reboot

RPi 1 will reboot now. Wait 1 minute.

Step 7: Transfer Updated Files to RPi 1 (Important!)
-----------------------------------------------------

Since you edited channel.py on Windows, transfer updated files:

1. In WinSCP (reconnect to 192.168.2.10 if needed)
2. Navigate to: C:\Users\ManishJadhav\OctoBoard\rpi_system\software\hardware\
3. Transfer these files to /home/pi/rpi_system/software/hardware/:
   - channel.py (the fixed version)
   - Any other files you modified

Step 8: Test RPi 1 Server
--------------------------

1. Reconnect PuTTY to 192.168.2.10

2. Login and run:

```bash
cd ~/rpi_system
source venv/bin/activate
./start_rpi.sh
```

Expected output:
```
🚀 Starting OctoBoard RPi API Server
=========================================
RPi ID: rpi_1
Main PC IP: 192.168.2.1
API Port: 8001
Simulation Mode: False
I2C Bus: 1
=========================================
✅ I2C enabled
📡 Scanning I2C devices...
(shows I2C scan - should show Octoboard addresses if connected)
✅ Main PC reachable
🚀 Starting API server...
Successfully initialized OBoard with I2C offset 0
Successfully initialized OBoard with I2C offset 1
Successfully initialized OBoard with I2C offset 2
INFO: Uvicorn running on http://0.0.0.0:8001
```

✅ RPi 1 is now running! Keep this PuTTY window open.

================================================================================
PART 4: RASPBERRY PI 2 SETUP (192.168.2.11)
================================================================================

Step 9: Connect to RPi 2 via PuTTY
-----------------------------------

1. Open NEW PuTTY window (don't close RPi 1 window)

2. Enter:
   - Host Name: 192.168.2.11
   - Port: 22
   - Connection type: SSH

3. Click "Open"

4. Login:
   - Username: pi
   - Password: raspberry (or your password)

Step 10: Transfer Files to RPi 2 via WinSCP
--------------------------------------------

1. Open NEW WinSCP session (or disconnect current and reconnect)

2. New Session:
   - File protocol: SFTP
   - Host name: 192.168.2.11
   - Port number: 22
   - User name: pi
   - Password: raspberry (or your password)

3. Click "Login"

4. In WinSCP:
   - Left panel (Windows): Navigate to C:\Users\ManishJadhav\OctoBoard\rpi_system
   - Right panel (RPi): Navigate to /home/pi/
   
5. Drag the entire "rpi_system" folder from left to right

6. Wait for transfer to complete (may take 2-5 minutes)

Step 11: Configure RPi 2 (in PuTTY)
------------------------------------

⚠️ IMPORTANT: RPi 2 needs DIFFERENT configuration!

Run these commands:

```bash
# Navigate to project
cd ~/rpi_system

# Edit the start script for RPi 2
nano start_rpi.sh
```

In nano editor:
1. Use arrow keys to navigate to line 6
2. Change:   export RPI_ID="${RPI_ID:-rpi_1}"
   To:       export RPI_ID="${RPI_ID:-rpi_2}"

3. Navigate to line 8
4. Change:   export API_PORT="${API_PORT:-8001}"
   To:       export API_PORT="${API_PORT:-8002}"

5. Line 7 should already be: export MAIN_PC_IP="${MAIN_PC_IP:-192.168.2.1}"

6. Save and exit:
   - Press Ctrl+O (save)
   - Press Enter (confirm)
   - Press Ctrl+X (exit)

Verify the changes:
```bash
cat start_rpi.sh | grep "export RPI_ID"
cat start_rpi.sh | grep "export MAIN_PC_IP"
cat start_rpi.sh | grep "export API_PORT"
```

Should show:
```
export RPI_ID="${RPI_ID:-rpi_2}"
export MAIN_PC_IP="${MAIN_PC_IP:-192.168.2.1}"
export API_PORT="${API_PORT:-8002}"
```

Continue setup:

```bash
# Make start script executable
chmod +x start_rpi.sh

# Create virtual environment
python3 -m venv venv

# Activate virtual environment
source venv/bin/activate

# Install Python packages (this takes 10-15 minutes)
pip install numpy>=1.22 fastapi>=0.104.0 uvicorn>=0.24.0 pydantic>=2.0.0 requests>=2.31.0 schedule>=1.2.0 adafruit-blinka>=7.3.3 adafruit-circuitpython-mcp4728>=1.0.8 adafruit-circuitpython-ads1x15>=2.3.9 adafruit-circuitpython-mcp230xx>=1.0.10
```

Wait for installation to complete...

```bash
# Enable I2C interface
sudo raspi-config
```

In raspi-config menu:
- Select: "3 Interface Options"
- Select: "I5 I2C"
- Select: "Yes" to enable
- Select: "Ok"
- Select: "Finish"
- Select: "Yes" to reboot

RPi 2 will reboot now. Wait 1 minute.

Step 12: Test RPi 2 Server
---------------------------

1. Reconnect PuTTY to 192.168.2.11

2. Login and run:

```bash
cd ~/rpi_system
source venv/bin/activate
./start_rpi.sh
```

Expected output:
```
🚀 Starting OctoBoard RPi API Server
=========================================
RPi ID: rpi_2
Main PC IP: 192.168.2.1
API Port: 8002
Simulation Mode: False
I2C Bus: 1
=========================================
✅ I2C enabled
📡 Scanning I2C devices...
(shows I2C scan)
✅ Main PC reachable
🚀 Starting API server...
Successfully initialized OBoard...
INFO: Uvicorn running on http://0.0.0.0:8002
```

✅ RPi 2 is now running! Keep this PuTTY window open.

================================================================================
PART 5: WINDOWS DASHBOARD CONFIGURATION
================================================================================

Step 13: Update Dashboard for 2 RPis
-------------------------------------

1. On Windows, open file:
   C:\Users\ManishJadhav\OctoBoard\main_pc_system\dashboard.py

2. Find line ~21 (look for RPIS = {)

3. Change from:
```python
RPIS = {
    "RPi 1": {"url": "http://192.168.2.10:8001", "id": "rpi_1"},
    # "RPi 2": {"url": "http://192.168.2.11:8002", "id": "rpi_2"},
    # "RPi 3": {"url": "http://192.168.2.12:8003", "id": "rpi_3"},
}
```

To:
```python
RPIS = {
    "RPi 1": {"url": "http://192.168.2.10:8001", "id": "rpi_1"},
    "RPi 2": {"url": "http://192.168.2.11:8002", "id": "rpi_2"},
    # "RPi 3": {"url": "http://192.168.2.12:8003", "id": "rpi_3"},  # Add when available
}
```

4. Save the file (Ctrl+S)

================================================================================
PART 6: START WINDOWS DASHBOARD AND FILE RECEIVER
================================================================================

Step 14: Start File Receiver
-----------------------------

1. Open PowerShell (Terminal 1)

2. Run:
```powershell
cd C:\Users\ManishJadhav\OctoBoard\main_pc_system
.\venv\Scripts\Activate.ps1
python file_receiver.py
```

Expected output:
```
INFO:     Started server process
INFO:     Waiting for application startup.
INFO:     Application startup complete.
INFO:     Uvicorn running on http://0.0.0.0:8000
```

✅ File receiver is running! Keep this window open.

Step 15: Start Dashboard
-------------------------

1. Open NEW PowerShell (Terminal 2)

2. Run:
```powershell
cd C:\Users\ManishJadhav\OctoBoard\main_pc_system
.\venv\Scripts\Activate.ps1
streamlit run dashboard.py
```

Expected output:
```
You can now view your Streamlit app in your browser.

Local URL: http://localhost:8501
Network URL: http://192.168.2.1:8501
```

3. Browser should open automatically to http://localhost:8501

✅ Dashboard is running!

================================================================================
PART 7: VERIFY EVERYTHING IS WORKING
================================================================================

Step 16: Check Dashboard
-------------------------

In the browser at http://localhost:8501:

1. Look at left sidebar under "Raspberry Pis"
   Should show:
   ✅ RPi 1 (with channel count)
   ✅ RPi 2 (with channel count)

2. Both should show green checkmarks and "Online" status

3. Check "System Overview" tab
   - Should show both RPis online
   - Total available channels
   - System capacity

Step 17: Test Ping from Windows
--------------------------------

Open PowerShell and test:
```powershell
ping 192.168.2.10
ping 192.168.2.11
```

Both should reply successfully!

================================================================================
PART 8: RUNNING MEASUREMENTS (WHEN READY)
================================================================================

Step 18: Connect Octoboards
----------------------------

1. Connect Octoboards to each Raspberry Pi via I2C
2. Restart each RPi server (in PuTTY):
   - Press Ctrl+C to stop
   - Run: ./start_rpi.sh
3. Check I2C scan output shows Octoboard addresses

Step 19: Start Your First Measurement
--------------------------------------

1. In Dashboard, go to "New Measurement" tab

2. Fill in:
   - Sample ID: TEST_001
   - Cell Area: 0.09 cm²
   - Current Limit: 50 mA
   - Start Voltage: 0 V
   - Stop Voltage: 1.2 V
   - Voltage Step: 0.01 V
   - Settle Time: 0.1 s
   - Sweep Interval: 60 minutes

3. Select Raspberry Pi (RPi 1 or RPi 2)
   - Channels will auto-assign

4. Click "🚀 Start Measurement"

5. Go to "Active Measurements" tab to monitor

6. Files will be saved to:
   C:\Users\ManishJadhav\SynologyDrive\Rayleigh\Outdoor Data\TEST_001\

================================================================================
TROUBLESHOOTING
================================================================================

Problem: Can't connect to RPi via PuTTY
----------------------------------------
Solution:
1. Check Ethernet cables are plugged in
2. Check switch has power
3. Verify Windows IP is 192.168.2.1 (run: ipconfig)
4. Try ping: ping 192.168.2.10

Problem: Dashboard shows RPis offline
--------------------------------------
Solution:
1. Check both RPi servers are running (PuTTY windows)
2. Verify dashboard.py has correct IPs and ports
3. Restart dashboard (Ctrl+C and run again)

Problem: File receiver not receiving files
-------------------------------------------
Solution:
1. Check file receiver is running on port 8000
2. Verify folder exists: C:\Users\ManishJadhav\SynologyDrive\Rayleigh\Outdoor Data
3. Check RPis can reach PC: ping 192.168.2.1 (from PuTTY)

Problem: I2C devices not detected
----------------------------------
Solution:
1. Check Octoboard power supply
2. Check I2C cables connected properly
3. Verify I2C enabled: sudo raspi-config
4. Reboot RPi: sudo reboot

================================================================================
NETWORK CONFIGURATION SUMMARY
================================================================================

Device          IP Address       Port    Purpose
-----------     --------------   -----   ---------------------------------
Windows PC      192.168.2.1      8000    File Receiver
Windows PC      192.168.2.1      8501    Dashboard (localhost)
RPi 1           192.168.2.10     8001    API Server (rpi_1)
RPi 2           192.168.2.11     8002    API Server (rpi_2)
Switch          N/A              N/A     Connects all devices

================================================================================
QUICK REFERENCE COMMANDS
================================================================================

On RPi (PuTTY):
---------------
cd ~/rpi_system
source venv/bin/activate
./start_rpi.sh                    # Start server
Ctrl+C                            # Stop server
nano start_rpi.sh                 # Edit configuration
sudo i2cdetect -y 1               # Scan I2C devices
sudo reboot                       # Reboot RPi

On Windows (PowerShell):
------------------------
cd C:\Users\ManishJadhav\OctoBoard\main_pc_system
.\venv\Scripts\Activate.ps1
python file_receiver.py           # Start file receiver
streamlit run dashboard.py        # Start dashboard
ping 192.168.2.10                # Test RPi 1 connection
ping 192.168.2.11                # Test RPi 2 connection
ipconfig                         # Check PC IP address

================================================================================
DAILY STARTUP ROUTINE
================================================================================

1. Power on both Raspberry Pis (wait 1 minute)

2. Start RPi 1 server:
   - PuTTY → 192.168.2.10
   - cd ~/rpi_system
   - source venv/bin/activate
   - ./start_rpi.sh

3. Start RPi 2 server:
   - PuTTY → 192.168.2.11
   - cd ~/rpi_system
   - source venv/bin/activate
   - ./start_rpi.sh

4. Start File Receiver (PowerShell):
   - cd C:\Users\ManishJadhav\OctoBoard\main_pc_system
   - .\venv\Scripts\Activate.ps1
   - python file_receiver.py

5. Start Dashboard (PowerShell):
   - cd C:\Users\ManishJadhav\OctoBoard\main_pc_system
   - .\venv\Scripts\Activate.ps1
   - streamlit run dashboard.py

6. Open browser: http://localhost:8501

7. Start measurements! 🚀

================================================================================
END OF SETUP GUIDE
================================================================================

Questions? Check the troubleshooting section or review specific steps above.

Your system is now ready to run outdoor solar cell testing with 2 Raspberry Pis!

Total Capacity:
- 2 RPis × 96 channels = 192 channels
- 48 samples max (4 pixels each)
- Automated IV sweeps every 1-1000 minutes
- Data auto-transferred to Windows PC

Good luck with your experiments! 🌞⚡

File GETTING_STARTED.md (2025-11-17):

# 🚀 Getting Started with OctoBoard v2.0

**Welcome!** This guide will get you up and running in 5 minutes.

---

## What You Have

A complete distributed system for testing 288 solar cell channels:
- **3 Raspberry Pis** (can simulate on Windows)
- **Main PC dashboard** for control and monitoring
- **Automated hourly measurements** with file transfer
- **Web interface** for easy operation

---

## Installation (First Time Only)

### Prerequisites
- Windows 10/11
- Python 3.9 or higher
- Web browser

### Step 1: Install Main PC System

Open PowerShell:

```powershell
cd C:\Users\ManishJadhav\OctoBoard\main_pc_system

# The start script will automatically:
# - Create virtual environment
# - Install all dependencies
# - Start both services
.\start.bat
```

**Expected:** Two terminal windows open + browser opens dashboard

### Step 2: Install RPi System (Simulation)

Open **new** PowerShell window:

```powershell
cd C:\Users\ManishJadhav\OctoBoard\rpi_system

# Run startup script
.\start.bat

# When asked: "Run in SIMULATION mode? (y/n):"
# Type: y
```

**Expected:** RPi API server starts in simulation mode

---

## First Measurement (5 Minutes)

### Step 1: Open Dashboard

Browser should automatically open to: **http://localhost:8501**

If not, manually open: http://localhost:8501

### Step 2: Check System Status

Look at the **left sidebar**:
- ✅ File Receiver should show "Online" (green)
- ✅ RPi 1 should show "Online" (green)

If red, click "🔄 Refresh Status" button

### Step 3: Start a Test Measurement

1. Click **"📝 New Measurement"** tab (at top)

2. Fill in **Sample Information:**
   - Sample ID: `Test_001`
   - Cell Area: `0.09` (leave default)
   - Current Limit: `50` (leave default)

3. Fill in **IV Sweep Parameters:**
   - All default values are fine for testing

4. Under **Hardware Assignment:**
   - Select Raspberry Pi: `RPi 1`
   - Select Channel Slot: `Slot 0: Channels 0-3`

5. Click **"🚀 Start Measurement"** button

**Expected:**
- Success message appears
- Green checkmark with details
- Message: "Data folder created"

### Step 4: Verify Active Measurement

1. Click **"📊 Active Measurements"** tab

2. You should see:
   - RPi 1 section
   - 📦 Test_001
   - Channels: 0-3
   - 🟢 Running
   - ⏹️ Stop button

### Step 5: Trigger First IV Sweep

**Option A: Wait 1 Hour** (normal operation)
- System will automatically run IV sweep after 1 hour

**Option B: Test Immediately** (modify temporarily)

In the RPi terminal, press `Ctrl+C` to stop.

Edit `rpi_system/api_server.py`:
```python
# Line ~250, find:
schedule.every(IV_SWEEP_INTERVAL_HOURS).hours.do(run_hourly_iv_sweeps)

# Change to:
schedule.every(10).seconds.do(run_hourly_iv_sweeps)
```

Restart: `python api_server.py`

Now IV sweep runs every 10 seconds instead!

### Step 6: Check Generated Files

After sweep runs (watch RPi terminal for messages):

```powershell
dir C:\OctoBoard_Data\Test_001\a\
```

**Expected:** CSV files like `IV_20240101_120530.csv`

### Step 7: Visualize Data

1. In dashboard, click **"📈 Data Visualization"** tab

2. Select Sample: `Test_001`

3. Select Pixel: `a`

4. Select latest CSV file

5. **See beautiful IV and Power curves!**

### Step 8: Stop Measurement

1. Go to **"📊 Active Measurements"** tab

2. Find `Test_001`

3. Click **"⏹️ Stop"** button

4. Confirm it disappears from active list

---

## Understanding the Dashboard

### 🏠 Sidebar (Left)
- **System Status** - Green = good, Red = problem
- **RPi List** - Shows all 3 Raspberry Pis
- **Active Samples** - Total count across all RPis
- **🔄 Refresh** - Update all statuses

### 📝 New Measurement Tab
- Configure new samples
- Assign to RPi and channel slot
- Start measurements

### 📊 Active Measurements Tab
- See all running measurements
- Stop measurements
- Real-time status

### 📁 Data Browser Tab
- Browse all samples
- See file counts per pixel
- Check latest files

### 📈 Data Visualization Tab
- Plot IV curves
- Plot Power curves
- See key metrics (Max Power, Voltage @ MPP)
- View raw data

---

## Understanding the Data

### Where Files Are Stored

```
C:\OctoBoard_Data\
└── Test_001\          ← Your Sample ID
    ├── a\             ← Pixel a (channel 0)
    │   └── IV_timestamp.csv
    ├── b\             ← Pixel b (channel 1)
    ├── c\             ← Pixel c (channel 2)
    └── d\             ← Pixel d (channel 3)
```

### CSV File Format

Each file contains IV sweep data:

```csv
voltage,current,power,timestamp
0.000,0.0450,0.0000,2024-01-01T12:05:30
0.010,0.0449,0.0004,2024-01-01T12:05:30
0.020,0.0448,0.0009,2024-01-01T12:05:30
...
1.200,0.0201,0.0241,2024-01-01T12:05:42
```

Columns:
- **voltage** - Applied voltage (V)
- **current** - Measured current (A)
- **power** - Calculated power (W) = voltage × current
- **timestamp** - When measurement taken

---

## System Capacity

| Metric | Value |
|---|---|
| Total Channels | 288 |
| Channels per RPi | 96 |
| Samples per RPi | 24 |
| Total Sample Capacity | 72 |
| Pixels per Sample | 4 (a, b, c, d) |
| Files Generated | 96/hour/RPi (288/hour total) |

---

## Common Questions

### Q: Do I need internet?
**A:** No! System works on local network (LAN) only.

### Q: Can I test without Raspberry Pi?
**A:** Yes! Use simulation mode (what you just did).

### Q: How do I add more samples?
**A:** Click "New Measurement" tab, use different Sample ID, select available slot.

### Q: What if I close the dashboard?
**A:** Just reopen browser to http://localhost:8501 - measurements keep running!

### Q: How do I stop everything?
**A:** Close both terminal windows (File Receiver and RPi API).

### Q: Where are the logs?
**A:** Check terminal windows for real-time logs.

### Q: Can I run multiple RPis?
**A:** Yes! Start multiple instances on different ports (8001, 8002, 8003).

---

## Next Steps

### For Development
- ✅ Tested simulation mode
- 📖 Read [TESTING_GUIDE.md](TESTING_GUIDE.md) for comprehensive testing
- 🔧 Modify IV parameters in dashboard
- 📊 Test with multiple samples

### For Production
- 📖 Read [main_pc_system/README.md](main_pc_system/README.md)
- 📖 Read [rpi_system/README.md](rpi_system/README.md)
- 🔧 Configure network (static IPs)
- 🔌 Deploy to actual Raspberry Pis
- 🧪 Test with real hardware
- ⚙️ Setup as system services

---

## Troubleshooting

### Dashboard Shows "File Receiver Offline" (Red)

**Solution:**
```powershell
# Check if running
curl http://localhost:8000/ping

# If not, start it
cd main_pc_system
.\start_receiver.bat
```

### Dashboard Shows "RPi 1 Offline" (Red)

**Solution:**
```powershell
# Check if running
curl http://localhost:8001/status

# If not, start it
cd rpi_system
.\start.bat
```

### No Files Appearing

**Solution:**
1. Check RPi terminal - did sweep run?
2. Check file receiver terminal - any errors?
3. Verify: `dir C:\OctoBoard_Data\Test_001\`
4. Try manually triggering sweep (10-second interval trick above)

### "No Available Slots" Error

**Solution:**
- All 24 slots occupied on that RPi
- Stop some measurements or select different RPi

---

## Quick Command Reference

```powershell
# Start everything
cd main_pc_system ; .\start.bat
cd rpi_system ; .\start.bat

# Check status
curl http://localhost:8000/ping          # File receiver
curl http://localhost:8001/status        # RPi 1

# View data
dir C:\OctoBoard_Data\                   # All samples
dir C:\OctoBoard_Data\Test_001\a\        # Specific pixel

# Test file receiver
curl -X POST http://localhost:8000/upload
```

---

## Documentation Index

| Document | Purpose |
|---|---|
| **This file** | Quick 5-minute start |
| [readme.md](readme.md) | Full project overview |
| [TESTING_GUIDE.md](TESTING_GUIDE.md) | Complete testing procedures |
| [PROJECT_STRUCTURE.md](PROJECT_STRUCTURE.md) | System architecture |
| [main_pc_system/README.md](main_pc_system/README.md) | Main PC setup & API |
| [rpi_system/README.md](rpi_system/README.md) | RPi setup & configuration |
| [IMPLEMENTATION_SUMMARY.md](IMPLEMENTATION_SUMMARY.md) | What was built |

---

## Support

Having issues?
1. Check terminal logs for error messages
2. Review troubleshooting section above
3. Read [TESTING_GUIDE.md](TESTING_GUIDE.md)
4. Check if ports are in use: `netstat -ano | findstr :8000`

---

## Success! 🎉

You've successfully:
- ✅ Installed OctoBoard v2.0
- ✅ Started main PC system
- ✅ Simulated a Raspberry Pi
- ✅ Configured and started a measurement
- ✅ Triggered an IV sweep
- ✅ Viewed generated data files
- ✅ Visualized IV curves

**You're ready to use OctoBoard!**

---

*Last Updated: January 2024*
*Version: 2.0*

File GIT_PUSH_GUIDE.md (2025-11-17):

# Git Push Instructions for OctoBoard v2.0

## Before You Push - Checklist

### ✅ Files to INCLUDE (Production Code):
- `rpi_system/` - All RPi code
  - `api_server.py` - Main API server
  - `start_rpi.sh` - Startup script
  - `requirements.txt` - Dependencies
  - `software/` - Hardware control code
- `main_pc_system/` - All Main PC code
  - `dashboard.py` - Streamlit dashboard
  - `file_receiver.py` - File receiver API
  - `requirements.txt` - Dependencies
- `docs/` - Documentation
- `hardware/` - PCB designs
- `examples/` - Example code
- `PRODUCTION_DEPLOYMENT.md` - Production guide
- `RPi_BEGINNER_GUIDE.md` - Beginner's guide
- `readme.md` - Main README
- `.gitignore` - Git ignore file

### ❌ Files to EXCLUDE (Already in .gitignore):
- `venv/` - Virtual environments
- `__pycache__/` - Python cache
- `*.pyc` - Compiled Python
- `data/` - Measurement data
- `IV/` - IV sweep data
- `tmp/` - Temporary files
- `.vscode/` - IDE settings

---

## Step-by-Step Git Push Commands

### 1. Check Current Status
```powershell
cd C:\Users\ManishJadhav\OctoBoard
git status
```

### 2. Add All Production Files
```powershell
# Add all files (respects .gitignore)
git add .

# Review what will be committed
git status
```

### 3. Commit Changes
```powershell
git commit -m "v2.0: Production-ready system with configurable intervals and auto-detection

- Added configurable IV sweep intervals (1-1000 minutes per sample)
- Implemented persistent state management with status files
- Added automatic hardware detection (1-12 Octoboards)
- Optimized dashboard with pagination for 288+ channels
- Created production deployment guides
- Added beginner's guide for Raspberry Pi setup
- Fixed channel assignment to prevent conflicts
- Updated file receiver to handle config and status files
- Added systemd service for auto-start
- Improved performance with caching and form optimization"
```

### 4. Push to GitHub
```powershell
# Push to main branch
git push origin main

# If this is the first push or branch doesn't exist
git push -u origin main
```

---

## Alternative: Stage Files Selectively

If you want to review each file before committing:

```powershell
# Add specific directories
git add rpi_system/
git add main_pc_system/
git add docs/
git add hardware/
git add examples/

# Add documentation files
git add readme.md
git add PRODUCTION_DEPLOYMENT.md
git add RPi_BEGINNER_GUIDE.md
git add .gitignore

# Check what's staged
git status

# Commit
git commit -m "v2.0: Production-ready release"

# Push
git push origin main
```

---

## What .gitignore Excludes

The `.gitignore` file prevents these from being pushed:
- Virtual environments (`venv/`, `env/`)
- Python cache (`__pycache__/`, `*.pyc`)
- IDE files (`.vscode/`, `.idea/`)
- Data files (`data/`, `IV/`, `*.csv`)
- Temporary files (`tmp/`, `*.tmp`)
- System files (`.DS_Store`, `Thumbs.db`)
- Logs (`*.log`)

---

## Verify Before Pushing

```powershell
# See what will be committed (excluding ignored files)
git diff --cached

# List all files that will be pushed
git ls-files
```

---

## After Pushing

### Verify on GitHub
1. Go to https://github.com/Manish4268/OctoBoard
2. Check that all files are present
3. Verify README displays correctly
4. Check documentation files are readable

### Tag the Release
```powershell
# Create a version tag
git tag -a v2.0.0 -m "Production-ready v2.0 release"
git push origin v2.0.0
```

---

## Quick Reference

### Full Push (One Command)
```powershell
cd C:\Users\ManishJadhav\OctoBoard
git add .
git commit -m "v2.0: Production-ready system"
git push origin main
```

### Check Remote
```powershell
git remote -v
```

### Force Push (Use with caution!)
```powershell
# Only if you need to overwrite remote
git push -f origin main
```

---

## Important Notes

1. **Data Safety**: The `.gitignore` prevents actual measurement data from being pushed
2. **Venv Excluded**: Virtual environments are not pushed - users will create their own
3. **Clean Code**: Only production-ready code will be pushed
4. **Documentation**: All guides and READMEs are included

---

## Files Structure That Will Be Pushed

```
OctoBoard/
├── .gitignore
├── readme.md
├── PRODUCTION_DEPLOYMENT.md
├── RPi_BEGINNER_GUIDE.md
├── docs/
│   ├── images/
│   └── videos/
├── hardware/
│   ├── Measurement Chuck Housing CAD Design/
│   ├── Measurement Chuck PCB Design/
│   └── Octoboard PCB Design/
├── examples/
│   ├── examples.md
│   └── GUI_Marburg/
├── rpi_system/
│   ├── api_server.py
│   ├── start_rpi.sh
│   ├── requirements.txt
│   └── software/
│       └── hardware/
│           ├── __init__.py
│           ├── channel.py
│           ├── constants.py
│           ├── i2c.py
│           ├── manager.py
│           ├── oboard.py
│           └── sdac.py
└── main_pc_system/
    ├── dashboard.py
    ├── file_receiver.py
    └── requirements.txt
```

**✅ Ready to push! All production code, no clutter!**

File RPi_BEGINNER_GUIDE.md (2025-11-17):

# 🎓 Complete Beginner's Guide to Raspberry Pi with OctoBoard

## 📋 Your Current Setup
- **Raspberry Pi** connected via **Ethernet cable** to your **Laptop**
- **1 Octoboard** connected to RPi's I2C pins
- **Laptop** running Windows with the dashboard

---

## 🔌 Step 1: Find Your Raspberry Pi's IP Address

### Option A: Using Your Router (Easiest)
1. Open your web browser
2. Go to your router's admin page (usually `192.168.1.1` or `192.168.0.1`)
3. Login (check router sticker for password)
4. Look for "Connected Devices" or "DHCP Clients"
5. Find device named "raspberrypi" - note its IP address (e.g., `192.168.1.150`)

### Option B: Using Windows Command Prompt
```powershell
# Open PowerShell and scan your network
arp -a

# Look for an entry like:
# 192.168.1.150    b8-27-eb-xx-xx-xx    dynamic
# The IP starting with b8-27-eb is likely your RPi
```

### Option C: Connect Monitor to RPi
1. Connect HDMI monitor and keyboard to RPi
2. Login (default: username=`pi`, password=`raspberry`)
3. Run command:
```bash
hostname -I
```
4. You'll see the IP address (e.g., `192.168.1.150`)

**Write down this IP address! Let's call it `<RPI_IP>`**

---

## 🔐 Step 2: Connect to Raspberry Pi via SSH

### What is SSH?
SSH lets you control your Raspberry Pi from your laptop's command line (no monitor needed!)

### Enable SSH on RPi (if not already enabled)
**If you have a monitor connected:**
```bash
sudo raspi-config
# Navigate to: Interface Options → SSH → Enable
```

**If you can't access RPi yet:**
- Take out the SD card
- Insert into your laptop
- Create an empty file named `ssh` (no extension) in the boot partition
- Put SD card back in RPi and boot

### Connect from Windows
1. **Open PowerShell** on your laptop
2. Type:
```powershell
ssh pi@<RPI_IP>
# Example: ssh pi@192.168.1.150
```

3. If asked "Are you sure?", type `yes`
4. **Default password:** `raspberry`

**✅ Success!** You should now see:
```
pi@raspberrypi:~ $
```

---

## 🌐 Step 3: Configure Network

### Check if RPi can access internet
```bash
ping google.com -c 4
# Press Ctrl+C to stop

# If it works, you'll see responses
# If not, your RPi needs internet access
```

### If RPi has no internet (direct laptop connection):
**Option 1: Share your laptop's WiFi with RPi**
1. On Windows: Settings → Network & Internet → Mobile hotspot → ON
2. Or connect RPi to same WiFi as laptop

**Option 2: Bridge connection (Advanced)**
- Share laptop's WiFi through Ethernet to RPi
- Not recommended for beginners

---

## 🛠️ Step 4: Setup Raspberry Pi

### Update System
```bash
# This takes 5-10 minutes
sudo apt update
sudo apt upgrade -y
```

### Install Python and Tools
```bash
# Install Python 3 and pip
sudo apt install python3 python3-pip python3-venv -y

# Install I2C tools
sudo apt install i2c-tools -y

# Install git (to download code)
sudo apt install git -y
```

### Enable I2C (for Octoboard communication)
```bash
sudo raspi-config
```

**Navigation:**
1. Use arrow keys to select: **3 Interface Options**
2. Press Enter
3. Select: **I5 I2C**
4. Select: **Yes**
5. Press Tab key to select **Finish**
6. **Reboot:** `sudo reboot`

**Wait 30 seconds**, then reconnect:
```powershell
ssh pi@<RPI_IP>
```

### Verify I2C is Enabled
```bash
ls /dev/i2c-*
# Should show: /dev/i2c-1
```

---

## 🔍 Step 5: Detect Your Octoboard

### Check I2C Devices
```bash
sudo i2cdetect -y 1
```

**What you should see:**
```
     0  1  2  3  4  5  6  7  8  9  a  b  c  d  e  f
00:          -- -- -- -- -- -- -- -- -- -- -- -- --
10:          -- -- -- -- -- -- -- -- -- -- -- -- -- -- -- --
20: 20 -- -- -- -- -- -- -- -- -- -- -- -- -- -- --
30:          -- -- -- -- -- -- -- -- -- -- -- -- -- -- -- --
40:          -- -- -- -- -- -- -- -- 48 -- -- -- -- -- -- --
50:          -- -- -- -- -- -- -- -- -- -- -- -- -- -- -- --
60: 60 61 -- -- -- -- -- -- -- -- -- -- -- -- -- --
70:          -- -- -- -- -- -- -- --
```

**Device addresses explained:**
- `20` = MCP23017 (I/O Expander) ✅
- `48` = ADS1115 (ADC) ✅
- `60`, `61` = MCP4728 (DAC) ✅

**If you see these addresses, your Octoboard is connected correctly!** 🎉

**If you see nothing or different addresses:**
- Check Octoboard is powered
- Check I2C wires (SDA, SCL, GND, 3.3V)
- Octoboard may have different I2C address offsets

---

## 📥 Step 6: Transfer OctoBoard Code to RPi

### Option A: Using Git (Recommended)
```bash
# Go to home directory
cd /home/pi

# Clone the repository
git clone https://github.com/Manish4268/OctoBoard.git

# Go into the rpi_system folder
cd OctoBoard/rpi_system
```

### Option B: Copy from Your Laptop
**On Windows PowerShell:**
```powershell
# Go to your OctoBoard folder
cd C:\Users\ManishJadhav\OctoBoard

# Copy rpi_system folder to RPi
scp -r rpi_system pi@<RPI_IP>:/home/pi/
```

**Then on RPi:**
```bash
cd /home/pi/rpi_system
```

---

## 🐍 Step 7: Setup Python Environment

```bash
# Make sure you're in rpi_system folder
cd /home/pi/rpi_system  # or /home/pi/OctoBoard/rpi_system

# Create virtual environment
python3 -m venv venv

# Activate it
source venv/bin/activate
# You should see (venv) before your prompt

# Upgrade pip
pip install --upgrade pip

# Install dependencies (takes 5-10 minutes)
pip install -r requirements.txt

# Install Adafruit libraries for I2C
pip install adafruit-circuitpython-busdevice
pip install adafruit-circuitpython-mcp4728
pip install adafruit-circuitpython-ads1x15
pip install adafruit-circuitpython-mcp230xx
```

---

## 🧪 Step 8: Test Hardware Detection

```bash
# Make sure venv is activated
source venv/bin/activate

# Test if code can detect your Octoboard
python3 -c "
from software import get_hardware_classes
print('Trying to detect Octoboards...')
OBoardManager, _, _, _ = get_hardware_classes()
manager = OBoardManager(i2c_num=1)
print(f'✅ SUCCESS! Detected {len(manager.oboards)} Octoboard(s)')
print(f'Total channels: {len(manager.oboards) * 8}')
"
```

**Expected output:**
```
Trying to detect Octoboards...
Found I2C devices at addresses: {32, 72, 96, 97}
Successfully initialized OBoard with I2C offset 0
✅ SUCCESS! Detected 1 Octoboard(s)
Total channels: 8
```

**If you see errors:**
- Check I2C is enabled: `ls /dev/i2c-*`
- Check permissions: `sudo usermod -a -G i2c pi` then logout/login
- Check Octoboard connections

---

## ⚙️ Step 9: Configure for Your Network

### Edit Configuration File
```bash
nano software/hardware/constants.py
```

**Find this line (around line 119):**
```python
MAIN_PC_IP = os.environ.get('MAIN_PC_IP', 'localhost')
```

**Press Ctrl+X, then Y, then Enter to save**

### Set Environment Variables
```bash
# Edit startup script
nano start_rpi.sh
```

**Change these lines:**
```bash
export MAIN_PC_IP="192.168.1.100"  # Change to YOUR laptop's IP
export RPI_ID="rpi_1"
export API_PORT="8001"
export OCTOBOARD_SIMULATION="False"  # Important: False = real hardware
```

**Save:** Ctrl+X → Y → Enter

### Make Script Executable
```bash
chmod +x start_rpi.sh
```

---

## 🖥️ Step 10: Find Your Laptop's IP Address

**On Windows PowerShell:**
```powershell
ipconfig
```

**Look for:**
```
Ethernet adapter Ethernet:
   IPv4 Address. . . . . . . . : 192.168.1.100
```

**Or:**
```
Wireless LAN adapter Wi-Fi:
   IPv4 Address. . . . . . . . : 192.168.1.100
```

**This is your `MAIN_PC_IP`!** Write it down!

---

## 🚀 Step 11: Start the RPi Server

### On Raspberry Pi:
```bash
# Go to folder
cd /home/pi/rpi_system

# Activate venv
source venv/bin/activate

# Run the startup script
./start_rpi.sh
```

**You should see:**
```
🚀 Starting OctoBoard RPi API Server
=========================================
RPi ID: rpi_1
Main PC IP: 192.168.1.100
API Port: 8001
Simulation Mode: False
I2C Bus: 1
=========================================
🔍 Checking I2C...
✅ I2C enabled
📡 Scanning I2C devices...
[shows i2cdetect output]
🌐 Testing connection to Main PC...
✅ Main PC reachable
🚀 Starting API server...
[rpi_1] Starting up...
[rpi_1] Simulation Mode: False
Found I2C devices at addresses: {32, 72, 96, 97}
Successfully initialized OBoard with I2C offset 0
[rpi_1] Initialized 1 boards
INFO:     Uvicorn running on http://0.0.0.0:8001
```

**✅ If you see this, RPi is READY!**

---

## 💻 Step 12: Configure Main PC (Your Laptop)

### Update Dashboard Settings
**Open:** `C:\Users\ManishJadhav\OctoBoard\main_pc_system\dashboard.py`

**Find (around line 20) and change:**
```python
RPIS = {
    "RPi 1": {"url": "http://<RPI_IP>:8001", "id": "rpi_1"},  # Change <RPI_IP>!
    # "RPi 2": {"url": "http://192.168.1.102:8002", "id": "rpi_2"},  # Comment out
    # "RPi 3": {"url": "http://192.168.1.103:8003", "id": "rpi_3"},  # Comment out
}
```

**Example (if RPi IP is 192.168.1.150):**
```python
RPIS = {
    "RPi 1": {"url": "http://192.168.1.150:8001", "id": "rpi_1"},
}
```

**Save the file**

---

## 🎯 Step 13: Start Everything

### On Laptop (Windows PowerShell):

**Terminal 1 - File Receiver:**
```powershell
cd C:\Users\ManishJadhav\OctoBoard\main_pc_system
.\venv\Scripts\Activate.ps1
python file_receiver.py
```

**Terminal 2 - Dashboard:**
```powershell
cd C:\Users\ManishJadhav\OctoBoard\main_pc_system
.\venv\Scripts\Activate.ps1
streamlit run dashboard.py
```

**Terminal 3 - Keep RPi running via SSH**

---

## ✅ Step 14: Test Everything!

### Open Dashboard
1. Browser opens automatically to `http://localhost:8501`
2. **Check sidebar:** Should show "✅ RPi 1" (green)
3. **Check channels:** Should show "8" channels

### Run First Measurement
1. Go to **"New Measurement"** tab
2. Enter Sample ID: `Test_001`
3. Select **RPi 1**
4. Should show: **"Assigned Channels: 0-3"**
5. Click **"Start Measurement"**

### Check Files Arrive
1. Open: `C:\Users\ManishJadhav\SynologyDrive\Rayleigh\Outdoor Data`
2. You should see folder: `Test_001`
3. Inside: `a/`, `b/`, `c/`, `d/` folders with `.csv` files
4. Also: `Config.txt` and `rpi_1_Samples_Status.txt`

**If files appear: 🎉 SUCCESS! Everything works!**

---

## 🔧 Troubleshooting

### Problem: "Connection refused" in dashboard
**Solution:**
```bash
# On RPi, check if server is running:
ps aux | grep python

# If not running, start it:
cd /home/pi/rpi_system
source venv/bin/activate
./start_rpi.sh
```

### Problem: "Cannot reach Main PC"
**Solution:**
```powershell
# On Windows: Allow port 8000 in firewall
# Or temporarily disable firewall for testing
```

### Problem: No files appearing
**Check:**
1. RPi terminal shows "Transferred" messages?
2. File receiver terminal shows "[DEBUG] Receiving file"?
3. Check IP addresses are correct

### Problem: "Board not available" errors
**Solution:**
```bash
# Check I2C again:
sudo i2cdetect -y 1

# Restart RPi if needed:
sudo reboot
```

---

## 🎓 Understanding the System

### What happens when you start a measurement:

1. **Dashboard (Laptop)** → Sends config to **RPi API** via HTTP
2. **RPi API** → Saves config, schedules IV sweeps
3. **RPi Hardware** → Performs IV sweep on 4 channels (a,b,c,d)
4. **RPi** → Saves data to local `/tmp/` folder
5. **RPi** → Transfers files to **File Receiver (Laptop)** via HTTP POST
6. **File Receiver** → Saves files to SynologyDrive folder
7. **Dashboard** → Reads files and displays charts

### The 3 Running Programs:

1. **RPi API Server** (Port 8001) - Controls hardware, runs measurements
2. **File Receiver** (Port 8000) - Receives files from RPi
3. **Dashboard** (Port 8501) - Web interface for you to control everything

---

## 📝 Quick Reference Commands

### SSH into RPi:
```powershell
ssh pi@<RPI_IP>
```

### Start RPi Server:
```bash
cd /home/pi/rpi_system
source venv/bin/activate
./start_rpi.sh
```

### Check RPi Server Status:
```bash
ps aux | grep python
```

### Stop RPi Server:
```bash
# Press Ctrl+C in the terminal where it's running
```

### View RPi Logs:
```bash
# While server is running, logs appear in terminal
```

### Reboot RPi:
```bash
sudo reboot
```

---

## 🚀 Next Steps

Once everything works:

1. **Set up Auto-Start:** Follow `PRODUCTION_DEPLOYMENT.md` → Step 7 (systemd service)
2. **Add More RPis:** Repeat process with different RPI_ID and API_PORT
3. **Add More Octoboards:** Just connect them - system auto-detects!

---

## 📞 Getting Help

If stuck:
1. Check which step failed
2. Read error messages carefully
3. Check the troubleshooting section
4. Google specific error messages

**Common files to check:**
- RPi: `/home/pi/rpi_system/api_server.py`
- Laptop: `C:\Users\ManishJadhav\OctoBoard\main_pc_system\dashboard.py`
- Config: `C:\Users\ManishJadhav\OctoBoard\rpi_system\software\hardware\constants.py`

---

**You're ready to go! Follow each step carefully and you'll have it working! 🎉**

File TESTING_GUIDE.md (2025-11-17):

# OctoBoard System - Complete Testing Guide

## Overview

This guide walks you through testing the complete OctoBoard system in **simulation mode** on Windows, without requiring Raspberry Pi hardware.

## System Architecture

```
┌─────────────────────────────────────────────────────────┐
│                    Main PC (192.168.1.100)              │
│  ┌─────────────────┐         ┌──────────────────────┐  │
│  │  File Receiver  │         │   Streamlit          │  │
│  │  Port: 8000     │◄────────┤   Dashboard          │  │
│  └────────▲────────┘         │   Port: 8501         │  │
│           │                  └──────────────────────┘  │
└───────────┼──────────────────────────────────────────────┘
            │
            │ HTTP POST (File Transfer)
            │
    ┌───────┴────────┬──────────────────┬────────────────┐
    │                │                  │                │
┌───▼────────┐  ┌────▼──────┐    ┌─────▼───────┐       │
│  RPi 1     │  │  RPi 2    │    │   RPi 3     │       │
│  .101:8001 │  │  .102:8001│    │   .103:8001 │       │
│            │  │           │    │             │       │
│ 96 chs     │  │ 96 chs    │    │ 96 chs      │       │
│ 24 samples │  │ 24 samples│    │ 24 samples  │       │
└────────────┘  └───────────┘    └─────────────┘       │
```

## Prerequisites

- Windows 10/11
- Python 3.9+
- PowerShell or Command Prompt
- Web browser

## Test Environment Setup

### Step 1: Install Main PC System

```powershell
# Navigate to main_pc_system
cd C:\Users\ManishJadhav\OctoBoard\main_pc_system

# Run startup script (will create venv and install deps)
.\start.bat
```

**Expected:** Two terminal windows open:
- "OctoBoard File Receiver" - Shows uvicorn server logs
- "OctoBoard Dashboard" - Opens browser at http://localhost:8501

### Step 2: Verify Main PC Services

**Test File Receiver:**
```powershell
curl http://localhost:8000/ping
```

**Expected Response:**
```json
{"status": "ok", "message": "File receiver is running"}
```

**Test Dashboard:**
- Open browser to `http://localhost:8501`
- Should see "OctoBoard Control Center" title
- Sidebar shows "File Receiver Online" with green checkmark

## Simulating Raspberry Pis

### Step 3: Start Simulated RPi 1

Open **new PowerShell terminal**:

```powershell
cd C:\Users\ManishJadhav\OctoBoard\rpi_system

# Create venv and install
python -m venv venv
.\venv\Scripts\Activate.ps1
pip install -r requirements.txt

# Set simulation mode
$env:OCTOBOARD_SIMULATION="True"

# Start API server
python api_server.py
```

**Expected Output:**
```
========================================
OctoBoard RPi API Server
========================================
Mode: SIMULATION
Total Boards: 12
Total Channels: 96
...
INFO:     Uvicorn running on http://0.0.0.0:8001
```

### Step 4: Verify RPi API

In **another terminal**:

```powershell
curl http://localhost:8001/status
```

**Expected Response:**
```json
{
  "status": "online",
  "total_channels": 96,
  "total_samples_capacity": 24,
  "active_samples": 0,
  "available_slots": 24
}
```

### Step 5: Check Dashboard Connection

1. Go to dashboard at `http://localhost:8501`
2. Click "🔄 Refresh Status" in sidebar
3. Should show "✅ RPi 1" with green status

⚠️ **Note:** If using localhost (127.0.0.1) for testing, you need to modify IP addresses:

**Option A: Use localhost for testing**
Edit `rpi_system/api_server.py`:
```python
MAIN_PC_IP = "127.0.0.1"  # Changed from 192.168.1.100
```

Edit `main_pc_system/dashboard.py`:
```python
RPIS = {
    "RPi 1": {"url": "http://127.0.0.1:8001", "id": "rpi_1"},
}
```

**Option B: Configure actual network IPs** (skip for basic testing)

## End-to-End Testing

### Test 1: Start a Measurement

1. **In Dashboard** → Go to "📝 New Measurement" tab

2. **Fill Sample Info:**
   - Sample ID: `Test_Sample_001`
   - Cell Area: `0.09` cm²
   - Current Limit: `50` mA

3. **Configure IV Sweep:**
   - Start Voltage: `0.0` V
   - Stop Voltage: `1.2` V
   - Voltage Step: `0.01` V
   - Settle Time: `0.1` s

4. **Select Hardware:**
   - Raspberry Pi: `RPi 1`
   - Channel Slot: `Slot 0: Channels 0-3` (or any available)

5. **Click "🚀 Start Measurement"**

**Expected:**
- Success message appears
- Shows assigned channels and configuration
- Folder created: `C:\OctoBoard_Data\Test_Sample_001\`
- With subfolders: `a/`, `b/`, `c/`, `d/`

### Test 2: Verify Active Measurement

1. **In Dashboard** → Go to "📊 Active Measurements" tab

2. **Check RPi 1 section:**
   - Should show `Test_Sample_001`
   - Status: "🟢 Running"
   - Channels: 0-3

### Test 3: Manual IV Sweep Trigger

In RPi terminal, you should see scheduled tasks:
```
INFO: Scheduled hourly IV sweep for Test_Sample_001
INFO: Next run at: 2024-01-01 13:00:00
```

To **manually trigger** IV sweep (for testing):

```powershell
# In RPi terminal, press Ctrl+C to stop
# Then modify api_server.py temporarily:

# Find this line:
schedule.every(IV_SWEEP_INTERVAL_HOURS).hours.do(run_hourly_iv_sweeps)

# Change to:
schedule.every(10).seconds.do(run_hourly_iv_sweeps)

# Restart:
python api_server.py
```

Now IV sweep will run every 10 seconds instead of every hour.

**Expected Behavior:**
1. RPi runs IV sweep on all 4 pixels (a, b, c, d)
2. Generates 4 CSV files
3. Transfers files to Main PC
4. Main PC saves to `C:\OctoBoard_Data\Test_Sample_001\{pixel}\`

### Test 4: Verify File Transfer

**Check RPi Logs:**
```
INFO: Running IV sweep for Test_Sample_001 (channels 0-3)
INFO: Pixel a: IV sweep complete, 121 points
INFO: Transferring file to Main PC...
INFO: Transfer successful: Test_Sample_001/a/IV_20240101_120530.csv
...
```

**Check File Receiver Logs:**
```
INFO: Received file upload: Test_Sample_001/a/IV_20240101_120530.csv
INFO: File saved successfully (12345 bytes)
```

**Check File System:**
```powershell
dir C:\OctoBoard_Data\Test_Sample_001\a\
```

Should show CSV files with timestamps.

### Test 5: Browse Data in Dashboard

1. **Dashboard** → "📁 Data Browser" tab
2. Select `Test_Sample_001` from dropdown
3. Should show all 4 pixels (a, b, c, d)
4. Each pixel should show file count
5. Latest file timestamp displayed

### Test 6: Visualize IV Curves

1. **Dashboard** → "📈 Data Visualization" tab
2. Select `Test_Sample_001`
3. Choose pixel (e.g., `a`)
4. Select most recent file
5. Should display:
   - IV Curve (Voltage vs Current)
   - Power Curve (Voltage vs Power)
   - Key metrics (Max Power, Voltage at MPP)

**Expected Plot:**
- Current increases with voltage (typical solar cell behavior)
- Power curve shows peak (maximum power point)
- Metrics calculated correctly

### Test 7: Stop Measurement

1. **Dashboard** → "📊 Active Measurements" tab
2. Find `Test_Sample_001`
3. Click "⏹️ Stop" button
4. Confirmation appears
5. Sample removed from active list

**Check RPi Logs:**
```
INFO: Stopping measurement for Test_Sample_001
INFO: Channels 0-3 released
INFO: Scheduler job removed
```

## Multi-RPi Testing (Optional)

### Start Multiple Simulated RPis

**Terminal 2 - RPi 2:**
```powershell
cd C:\Users\ManishJadhav\OctoBoard\rpi_system
.\venv\Scripts\Activate.ps1
$env:OCTOBOARD_SIMULATION="True"
$env:RPI_PORT="8002"  # Different port for local testing
python api_server.py
```

**Terminal 3 - RPi 3:**
```powershell
cd C:\Users\ManishJadhav\OctoBoard\rpi_system
.\venv\Scripts\Activate.ps1
$env:OCTOBOARD_SIMULATION="True"
$env:RPI_PORT="8003"  # Different port for local testing
python api_server.py
```

**Update Dashboard URLs:**
Edit `main_pc_system/dashboard.py`:
```python
RPIS = {
    "RPi 1": {"url": "http://127.0.0.1:8001", "id": "rpi_1"},
    "RPi 2": {"url": "http://127.0.0.1:8002", "id": "rpi_2"},
    "RPi 3": {"url": "http://127.0.0.1:8003", "id": "rpi_3"},
}
```

Restart dashboard to see all 3 RPis online.

## Common Issues & Solutions

### Issue 1: File Receiver Shows Offline

**Symptoms:** Red "❌ File Receiver Offline" in dashboard sidebar

**Solution:**
```powershell
# Check if receiver is running
curl http://localhost:8000/ping

# If not responding, restart:
cd main_pc_system
.\start_receiver.bat
```

### Issue 2: RPi Shows Offline in Dashboard

**Symptoms:** Red "❌ RPi 1 (Offline)"

**Solutions:**
1. Check RPi terminal - is server running?
2. Verify URLs in dashboard.py match RPi ports
3. Test RPi endpoint directly:
   ```powershell
   curl http://localhost:8001/status
   ```

### Issue 3: Files Not Appearing

**Symptoms:** IV sweep runs but no files in data folder

**Check:**
1. File receiver logs - any errors?
2. RPi logs - did transfer succeed?
3. Folder permissions on `C:\OctoBoard_Data\`
4. Main PC IP configured correctly in RPi

**Debug:**
```powershell
# Check receiver stats
curl http://localhost:8000/stats

# Should show files_received > 0
```

### Issue 4: "No Available Slots" Error

**Symptoms:** Cannot start measurement, all slots occupied

**Solution:**
Stop existing measurements or restart RPi server:
```powershell
# In RPi terminal, press Ctrl+C
# Restart:
python api_server.py
```

### Issue 5: Import Errors

**Symptoms:** `ModuleNotFoundError: No module named 'fastapi'`

**Solution:**
```powershell
# Activate venv and reinstall
.\venv\Scripts\Activate.ps1
pip install -r requirements.txt
```

## Performance Testing

### Test Data Generation Rate

**Measure files per minute:**
```powershell
# Get initial count
$before = (Get-ChildItem C:\OctoBoard_Data\Test_Sample_001\a\).Count

# Wait 1 minute (with 10-second interval)

# Get final count
$after = (Get-ChildItem C:\OctoBoard_Data\Test_Sample_001\a\).Count

# Calculate rate
$rate = $after - $before
Write-Host "Files per minute: $rate"
```

**Expected:** 6 files/minute (10-second interval)

### Test Dashboard Responsiveness

1. Start 10+ measurements across RPis
2. Navigate between tabs
3. Refresh status multiple times
4. Check lag or delays

**Expected:** < 2 seconds for page loads

## Data Validation

### Verify IV Curve Quality

Open generated CSV file:
```powershell
notepad C:\OctoBoard_Data\Test_Sample_001\a\IV_<timestamp>.csv
```

**Check:**
- Voltage range: 0.0 V to 1.2 V
- Voltage steps: ~0.01 V intervals
- Current values: Reasonable (0-50 mA)
- No NaN or null values
- Power = voltage × current

**Sample Data:**
```csv
voltage,current,power,timestamp
0.000,0.0450,0.0000,2024-01-01T12:05:30
0.010,0.0449,0.0004,2024-01-01T12:05:30
0.020,0.0448,0.0009,2024-01-01T12:05:30
...
```

## System Limits Testing

### Test Maximum Capacity

1. Start 24 measurements on RPi 1 (all slots)
2. Verify dashboard shows "24/24" active
3. Try starting 25th measurement
4. Should show "No available slots" error

### Test File Transfer Under Load

1. Configure all 3 RPis with 10-second sweep interval
2. Start 24 samples on each RPi
3. Wait for sweeps to execute simultaneously
4. Monitor file receiver logs

**Expected:**
- 288 files transferred (72 samples × 4 pixels)
- All transfers succeed
- No timeouts or errors

## Production Deployment Testing

### Test on Actual Network

1. Configure Main PC with static IP: `192.168.1.100`
2. Configure RPis with IPs: `.101`, `.102`, `.103`
3. Update `api_server.py` and `dashboard.py` with real IPs
4. Test connectivity:
   ```bash
   # From Main PC
   ping 192.168.1.101
   curl http://192.168.1.101:8001/status
   ```

### Test Hardware Mode

On actual Raspberry Pi:
```bash
cd /home/pi/OctoBoard/rpi_system

# DO NOT set OCTOBOARD_SIMULATION
python api_server.py
```

Should connect to real hardware (MCP4728, ADS1115, etc.)

## Automated Testing Script

Save as `test_system.ps1`:

```powershell
# OctoBoard System Test Script

Write-Host "========================================" -ForegroundColor Cyan
Write-Host "OctoBoard System Test" -ForegroundColor Cyan
Write-Host "========================================" -ForegroundColor Cyan

# Test 1: File Receiver
Write-Host "`n[Test 1] Checking File Receiver..." -ForegroundColor Yellow
try {
    $response = Invoke-RestMethod -Uri "http://localhost:8000/ping"
    Write-Host "✅ PASS: File Receiver online" -ForegroundColor Green
} catch {
    Write-Host "❌ FAIL: File Receiver offline" -ForegroundColor Red
    exit 1
}

# Test 2: RPi 1
Write-Host "`n[Test 2] Checking RPi 1..." -ForegroundColor Yellow
try {
    $response = Invoke-RestMethod -Uri "http://localhost:8001/status"
    Write-Host "✅ PASS: RPi 1 online ($($response.total_channels) channels)" -ForegroundColor Green
} catch {
    Write-Host "❌ FAIL: RPi 1 offline" -ForegroundColor Red
    exit 1
}

# Test 3: Data Directory
Write-Host "`n[Test 3] Checking Data Directory..." -ForegroundColor Yellow
if (Test-Path "C:\OctoBoard_Data") {
    Write-Host "✅ PASS: Data directory exists" -ForegroundColor Green
} else {
    Write-Host "❌ FAIL: Data directory missing" -ForegroundColor Red
    exit 1
}

Write-Host "`n========================================" -ForegroundColor Cyan
Write-Host "All tests passed! ✅" -ForegroundColor Green
Write-Host "========================================" -ForegroundColor Cyan
```

Run:
```powershell
.\test_system.ps1
```

## Success Criteria

Complete system is working correctly when:

- ✅ File receiver responds to /ping
- ✅ All RPis show "Online" in dashboard
- ✅ Can start new measurements
- ✅ IV sweeps execute on schedule
- ✅ Files transfer automatically to Main PC
- ✅ Files appear in correct folder structure
- ✅ Dashboard displays all active measurements
- ✅ Data visualization plots IV curves correctly
- ✅ Can stop measurements cleanly
- ✅ System handles 72 concurrent samples

## Next Steps

After successful testing:

1. **Configure Production Network**: Set static IPs on Main PC and RPis
2. **Deploy to Hardware**: Transfer code to Raspberry Pis
3. **Test with Real Hardware**: Verify MCP4728, ADS1115 connections
4. **Calibration**: Adjust voltage/current ranges for actual cells
5. **Long-term Testing**: Run 24+ hour test to verify stability
6. **Backup Strategy**: Implement automated data backup

## Support

If tests fail, check:
- Terminal logs for error messages
- Network connectivity
- Port availability
- Python dependencies
- File permissions

For persistent issues, review code in:
- `rpi_system/api_server.py`
- `main_pc_system/file_receiver.py`
- `main_pc_system/dashboard.py`

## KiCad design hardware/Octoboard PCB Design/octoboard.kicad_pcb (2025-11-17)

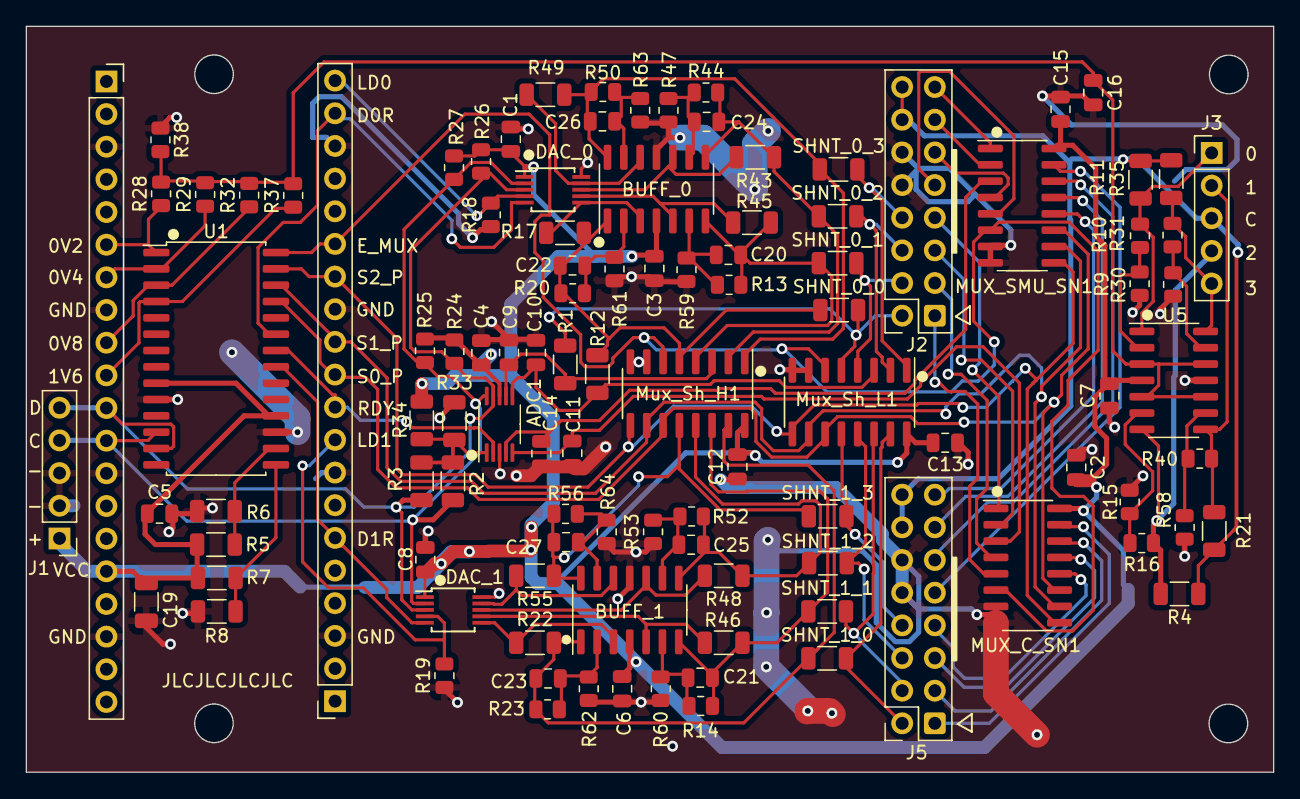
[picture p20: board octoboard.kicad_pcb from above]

Board: 2 copper layers, 97.0 x 58.0 mm, 107 parts (0 on the bottom side), 82 nets.

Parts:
ADC1: ADS1115IDGS; VSSOP-10_3x3mm_P0.5mm
BUFF_0, BUFF_1: LMV324; SOIC-14_3.9x8.7mm_P1.27mm
C1, C2, C3, C4, C5, C6, C7, C8, C9, C10, C11, C12, C13, C14, C15, C16: 0.1µ; C_0805_2012Metric
C19: 1µ; C_1206_3216Metric
C20, C21, C22, C23, C24, C25, C26, C27: 22p; C_0805_2012Metric
DAC_0, DAC_1: MCP4728; MSOP-10_3x3mm_P0.5mm
J1, J3: Conn_01x05_Pin; PinHeader_1x05_P2.54mm_Vertical
J2, J5: Conn_02x08_Odd_Even; IDC-Header_2x08_P2.54mm_Vertical_NO_SHROUD
MUX_C_SN1: 74HC4051; SOIC-16_3.9x9.9mm_P1.27mm
MUX_SMU_SN1: 74HC4051; SOIC-16_3.9x9.9mm_P1.27mm
Mux_Sh_H1: 74HC4051; SOIC-16_3.9x9.9mm_P1.27mm
Mux_Sh_L1: 74HC4051; SOIC-16_3.9x9.9mm_P1.27mm
R1, R2, R3, R5, R6, R7, R8, R12, R17, R22, R33, R34, R43, R45, R46, R48, R49, R55: 0; R_1206_3216Metric
R4, R11, R21, R35: 10; R_1206_3216Metric
R9, R10, R13, R14, R15, R16, R20, R23, R30, R31, R40, R44, R47, R50, R52, R53, R56, R58, R59, R60, R61, R62, R63, R64: 12k; R_0805_2012Metric
R18, R19, R28: 47k; R_0805_2012Metric
R24, R25, R26, R27, R37: 4.7K; R_0805_2012Metric
R29: 22k; R_0805_2012Metric
R32, R38: 10k; R_0805_2012Metric
RPI_20, RPI_40: Conn_01x20_Female; PinSocket_1x20_P2.54mm_Vertical
SHNT_0_0, SHNT_0_1, SHNT_0_2, SHNT_0_3, SHNT_1_0, SHNT_1_1, SHNT_1_2, SHNT_1_3: 20; R_1206_3216Metric
U1: MCP23017_SO; SOIC-28W_7.5x17.9mm_P1.27mm
U5: LMV324DR2G; SOIC-14_3.9x8.7mm_P1.27mm

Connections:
+3.3V: ADC1.8 (VDD), BUFF_0.4 (V+), BUFF_1.4 (V+), C1.2, C2.2, C3.2, C4.1, C5.1, C6.2, C7.2, C8.2, C12.2, C13.2, C15.2, C19.2, DAC_0.1 (VDD), DAC_1.1 (VDD), J1.1, MUX_C_SN1.16 (VCC), MUX_SMU_SN1.16 (VCC), Mux_Sh_H1.16 (VCC), Mux_Sh_L1.16 (VCC), R5.2, R7.2, R24.2, R25.2, R26.2, R27.2, R34.2, RPI_20.16, U1.9 (VDD), U1.18 (~RESET), U5.4 (V+)
A0_mult: ADC1.4 (AIN0), C14.2, MUX_SMU_SN1.3 (A)
A1_mult: ADC1.5 (AIN1), C11.2, MUX_C_SN1.3 (A)
A2_mult: ADC1.6 (AIN2), C10.2, Mux_Sh_L1.3 (A), R12.1
A3_mult: ADC1.7 (AIN3), C9.2, Mux_Sh_H1.3 (A), R1.1
ADC_1_RDY: ADC1.2 (ALERT/RDY), RPI_40.10, U1.22 (GPA1)
C_SENS_0_0: J2.1, MUX_C_SN1.5 (A5)
C_SENS_0_1: J2.3, MUX_C_SN1.4 (A7)
C_SENS_0_2: J2.5, MUX_C_SN1.2 (A6)
C_SENS_0_3: J2.7, MUX_C_SN1.1 (A4)
C_SENS_1_0: J5.1, MUX_C_SN1.15 (A2)
C_SENS_1_1: J5.3, MUX_C_SN1.14 (A1)
C_SENS_1_2: J5.5, MUX_C_SN1.13 (A0)
C_SENS_1_3: J5.7, MUX_C_SN1.12 (A3)
DAC_0_LDAC: DAC_0.4 (~LDAC), R18.2, RPI_40.20
DAC_0_RDY: DAC_0.5 (RDY/~BSY), RPI_40.19, U1.23 (GPA2)
DAC_1_LDAC: DAC_1.4 (~LDAC), R19.2, RPI_40.9
DAC_1_RDY: DAC_1.5 (RDY/~BSY), RPI_40.6, U1.21 (GPA0)
DAC_BUFF_0_0: BUFF_0.1, C22.2, Mux_Sh_H1.5 (A5), R12.2, R17.2, R20.2, SHNT_0_0.1
DAC_BUFF_0_1: BUFF_0.7, C20.2, Mux_Sh_H1.4 (A7), R13.2, R45.2, SHNT_0_1.1
DAC_BUFF_0_2: BUFF_0.8, C24.2, Mux_Sh_H1.2 (A6), R43.2, R44.2, SHNT_0_2.1
DAC_BUFF_0_3: BUFF_0.14, C26.2, Mux_Sh_H1.1 (A4), R49.2, R50.2, SHNT_0_3.1
DAC_BUFF_1_0: BUFF_1.1, C23.2, Mux_Sh_H1.15 (A2), R22.2, R23.2, SHNT_1_0.1
DAC_BUFF_1_1: BUFF_1.7, C21.2, Mux_Sh_H1.14 (A1), R14.2, R46.2, SHNT_1_1.1
DAC_BUFF_1_2: BUFF_1.8, C25.2, Mux_Sh_H1.13 (A0), R48.2, R52.2, SHNT_1_2.1
DAC_BUFF_1_3: BUFF_1.14, C27.2, Mux_Sh_H1.12 (A3), R55.2, R56.2, SHNT_1_3.1
E_mult_1: MUX_C_SN1.6 (~E), MUX_SMU_SN1.6 (~E), Mux_Sh_H1.6 (~E), Mux_Sh_L1.6 (~E), RPI_40.15, U1.28 (GPA7)
GND: ADC1.3 (GND), BUFF_0.11 (V-), BUFF_1.11 (V-), C1.1, C2.1, C3.1, C4.2, C5.2, C6.1, C7.1, C8.1, C9.1, C10.1, C11.1, C12.1, C13.1, C14.1, C15.1, C16.2, C19.1, DAC_0.10 (VSS), DAC_1.10 (VSS), J1.2, J1.3, J2.10, J2.12, J5.10, J5.12, MUX_C_SN1.7 (VEE), MUX_C_SN1.8 (GND), MUX_SMU_SN1.7 (VEE), MUX_SMU_SN1.8 (GND), Mux_Sh_H1.7 (VEE), Mux_Sh_H1.8 (GND), Mux_Sh_L1.7 (VEE), Mux_Sh_L1.8 (GND), R6.1, R8.1, R9.1, R15.1, R18.1, R19.1, R30.1, R33.2, R38.1, R47.1, R53.1, R58.1, R59.1, R60.1, R61.1, R62.1, R63.1, R64.1, RPI_20.3, RPI_20.8, RPI_20.13, RPI_20.18, RPI_40.3, RPI_40.8, RPI_40.13, RPI_40.18, U1.10 (VSS), U1.17 (A2), U5.11 (V-)
I2C0_SCL: ADC1.10 (SCL), DAC_0.2 (SCL), DAC_1.2 (SCL), J1.4, R2.2, R25.1, R27.1, RPI_20.12, U1.12 (SCK)
I2C0_SDA: ADC1.9 (SDA), DAC_0.3 (SDA), DAC_1.3 (SDA), J1.5, R3.2, R24.1, R26.1, RPI_20.11, U1.13 (SDA)
unnamed: ADC1.1 (ADDR), R2.1, R3.1, R33.1, R34.1
unnamed: BUFF_0.3 (+), DAC_0.6 (VOUTA), R17.1
unnamed: BUFF_0.2 (-), C22.1, R20.1, R61.2
unnamed: BUFF_0.5 (+), DAC_0.7 (VOUTB), R45.1
unnamed: BUFF_0.6 (-), C20.1, R13.1, R59.2
unnamed: BUFF_0.10 (+), DAC_0.8 (VOUTC), R43.1
unnamed: BUFF_0.9 (-), C24.1, R44.1, R47.2
unnamed: BUFF_0.12 (+), DAC_0.9 (VOUTD), R49.1
unnamed: BUFF_0.13 (-), C26.1, R50.1, R63.2
unnamed: BUFF_1.3 (+), DAC_1.6 (VOUTA), R22.1
unnamed: BUFF_1.2 (-), C23.1, R23.1, R62.2
unnamed: BUFF_1.5 (+), DAC_1.7 (VOUTB), R46.1
unnamed: BUFF_1.6 (-), C21.1, R14.1, R60.2
unnamed: BUFF_1.10 (+), DAC_1.8 (VOUTC), R48.1
unnamed: BUFF_1.9 (-), C25.1, R52.1, R53.2
unnamed: BUFF_1.12 (+), DAC_1.9 (VOUTD), R55.1
unnamed: BUFF_1.13 (-), C27.1, R56.1, R64.2
unnamed: R7.1, R8.2, U1.15 (A0)
unnamed: R5.1, R6.2, U1.16 (A1)
unnamed: C16.1, R28.2, R29.2, R32.2, R37.2, R38.2, U5.3 (+), U5.5 (+), U5.10 (+), U5.12 (+)
unnamed: R9.2, R10.1, U5.2 (-)
unnamed: R15.2, R16.1, U5.6 (-)
unnamed: R40.1, R58.2, U5.9 (-)
unnamed: R30.2, R31.1, U5.13 (-)
S0_PLX: MUX_C_SN1.11 (S0), MUX_SMU_SN1.11 (S0), Mux_Sh_H1.11 (S0), Mux_Sh_L1.11 (S0), RPI_40.11, U1.25 (GPA4)
S1_PLX: MUX_C_SN1.10 (S1), MUX_SMU_SN1.10 (S1), Mux_Sh_H1.10 (S1), Mux_Sh_L1.10 (S1), RPI_40.12, U1.26 (GPA5)
S2_PLX: MUX_C_SN1.9 (S2), MUX_SMU_SN1.9 (S2), Mux_Sh_H1.9 (S2), Mux_Sh_L1.9 (S2), RPI_40.14, U1.27 (GPA6)
SDAC_A_0V2: R28.1, RPI_20.6, U1.1 (GPB0)
SDAC_A_0V4: R29.1, RPI_20.7, U1.2 (GPB1)
SDAC_B_0V8: R32.1, RPI_20.9, U1.3 (GPB2)
SDAC_B_1V6: R37.1, RPI_20.10, U1.4 (GPB3)
SDAC_V0: J3.1, R10.2, R11.2, U5.1
SDAC_V1: J3.2, R21.2, R40.2, U5.8
SDAC_V2: J3.4, R4.2, R16.2, U5.7
SDAC_V3: J3.5, R31.2, R35.2, U5.14
SMU_Common: J2.14, J2.16, J3.3, J5.14, J5.16, R4.1, R11.1, R21.1, R35.1
SMU_OUT_0_0: J2.2, Mux_Sh_L1.5 (A5), R1.2, SHNT_0_0.2
SMU_OUT_0_1: J2.4, Mux_Sh_L1.4 (A7), SHNT_0_1.2
SMU_OUT_0_2: J2.6, Mux_Sh_L1.2 (A6), SHNT_0_2.2
SMU_OUT_0_3: J2.8, Mux_Sh_L1.1 (A4), SHNT_0_3.2
SMU_OUT_1_0: J5.2, Mux_Sh_L1.15 (A2), SHNT_1_0.2
SMU_OUT_1_1: J5.4, Mux_Sh_L1.14 (A1), SHNT_1_1.2
SMU_OUT_1_2: J5.6, Mux_Sh_L1.13 (A0), SHNT_1_2.2
SMU_OUT_1_3: J5.8, Mux_Sh_L1.12 (A3), SHNT_1_3.2
SMU_SENS_0_0: J2.9, MUX_SMU_SN1.5 (A5)
SMU_SENS_0_1: J2.11, MUX_SMU_SN1.4 (A7)
SMU_SENS_0_2: J2.13, MUX_SMU_SN1.2 (A6)
SMU_SENS_0_3: J2.15, MUX_SMU_SN1.1 (A4)
SMU_SENS_1_0: J5.9, MUX_SMU_SN1.15 (A2)
SMU_SENS_1_1: J5.11, MUX_SMU_SN1.14 (A1)
SMU_SENS_1_2: J5.13, MUX_SMU_SN1.13 (A0)
SMU_SENS_1_3: J5.15, MUX_SMU_SN1.12 (A3)

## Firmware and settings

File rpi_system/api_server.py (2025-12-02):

"""
Raspberry Pi API Server
- Controls 96 channels (12 Octoboards × 8 channels)
- Handles 24 samples (each sample = 4 pixels = 4 channels)
- Hourly IV sweep generation
- Automatic file transfer to Main PC
"""

from fastapi import FastAPI, HTTPException, BackgroundTasks, File, UploadFile
from pydantic import BaseModel
from typing import Optional, List, Dict
import uvicorn
import os
import threading
import time
import requests
import schedule
from datetime import datetime
from pathlib import Path

# Set simulation mode from environment
os.environ.setdefault('OCTOBOARD_SIMULATION', 'False')

from software.hardware.constants import (
    SIMULATION_MODE, 
    TOTAL_CHANNELS_PER_RPI, 
    SAMPLES_PER_RPI,
    PIXELS_PER_SAMPLE,
    IV_SWEEP_INTERVAL_HOURS,
    MAIN_PC_IP,
    MAIN_PC_PORT,
    FILE_TRANSFER_TIMEOUT
)
from software import get_hardware_classes

app = FastAPI(title="OctoBoard RPi API", version="2.0.0")

# Global state
board_manager = None
measurement_tasks = {}  # {sample_id: {pixel: {status, start_time, ...}}}
sample_configs = {}  # {sample_id: MeasurementConfig}
rpi_id = os.environ.get('RPI_ID', 'rpi_1')

# ==================== Data Models ====================

class MeasurementConfig(BaseModel):
    """Configuration for measuring a sample (4 pixels)."""
    sample_id: str
    start_channel: int  # Starting channel (0-95), will use this + 3 channels
    cell_area: float  # cm²
    current_limit: float  # mA
    start_voltage: float  # V
    stop_voltage: float  # V
    voltage_step: float  # V
    settle_time: float  # seconds
    sweep_interval_minutes: int = 60  # IV sweep interval in minutes (1-1000)
    measurement_type: str = "iv_sweep"  # or "mppt"
    mppt_iterations: Optional[int] = 100
    mppt_interval: Optional[float] = 0.01


class RPiStatus(BaseModel):
    """Status of this Raspberry Pi."""
    rpi_id: str
    simulation_mode: bool
    total_channels: int
    total_samples_capacity: int
    active_samples: int
    main_pc_connected: bool


# ==================== Hardware Initialization ====================

@app.on_event("startup")
async def startup_event():
    """Initialize hardware and start scheduler."""
    global board_manager
    
    print(f"[{rpi_id}] Starting up...")
    print(f"[{rpi_id}] Simulation Mode: {SIMULATION_MODE}")
    print(f"[{rpi_id}] Total Channels: {TOTAL_CHANNELS_PER_RPI}")
    print(f"[{rpi_id}] Sample Capacity: {SAMPLES_PER_RPI}")
    
    # Initialize hardware
    OBoardManager, _, _, _ = get_hardware_classes()
    i2c_num = int(os.environ.get('OCTOBOARD_I2C_BUS', '1'))
    board_manager = OBoardManager(i2c_num=i2c_num)
    
    print(f"[{rpi_id}] Initialized {len(board_manager.oboards)} boards")
    
    # Start scheduler thread for periodic IV sweeps
    scheduler_thread = threading.Thread(target=run_scheduler, daemon=True)
    scheduler_thread.start()
    print(f"[{rpi_id}] Scheduler started (per-sample intervals)")


def run_scheduler():
    """Run the scheduler in background thread - checks every minute."""
    while True:
        schedule.run_pending()
        time.sleep(60)  # Check every minute


# ==================== API Endpoints ====================

@app.get("/")
async def root():
    """Root endpoint."""
    return {
        "name": "OctoBoard RPi API",
        "rpi_id": rpi_id,
        "version": "2.0.0",
        "simulation_mode": SIMULATION_MODE,
        "channels": TOTAL_CHANNELS_PER_RPI,
        "samples_capacity": SAMPLES_PER_RPI
    }


@app.get("/status", response_model=RPiStatus)
async def get_status():
    """Get current status."""
    # Test Main PC connection
    main_pc_connected = test_main_pc_connection()
    
    # Report actual available channels based on connected boards
    actual_channels = len(board_manager.oboards) * 8 if board_manager else 0
    actual_samples_capacity = actual_channels // 4
    
    return RPiStatus(
        rpi_id=rpi_id,
        simulation_mode=SIMULATION_MODE,
        total_channels=actual_channels,  # Actual available channels
        total_samples_capacity=actual_samples_capacity,  # Actual sample capacity
        active_samples=len(sample_configs),
        main_pc_connected=main_pc_connected
    )


@app.get("/channels")
async def list_channels():
    """List all 96 channels grouped by samples."""
    channels = []
    
    for sample_num in range(SAMPLES_PER_RPI):
        start_ch = sample_num * PIXELS_PER_SAMPLE
        sample_channels = []
        
        for pixel_idx, pixel_name in enumerate(['a', 'b', 'c', 'd']):
            ch_idx = start_ch + pixel_idx
            board_idx = ch_idx // 8
            local_ch = ch_idx % 8
            
            sample_channels.append({
                "pixel": pixel_name,
                "channel_index": ch_idx,
                "board_index": board_idx,
                "local_channel": local_ch,
                "status": "active" if is_channel_active(ch_idx) else "idle"
            })
        
        channels.append({
            "sample_slot": sample_num,
            "start_channel": start_ch,
            "channels": sample_channels,
            "assigned_sample": get_assigned_sample(start_ch)
        })
    
    return {"total_sample_slots": SAMPLES_PER_RPI, "samples": channels}


@app.post("/measurement/start")
async def start_measurement(config: MeasurementConfig, background_tasks: BackgroundTasks):
    """Start measuring a sample (4 pixels on 4 consecutive channels)."""
    
    # Check actual available channels based on connected boards
    actual_channels = len(board_manager.oboards) * 8 if board_manager else 0
    
    # Validate channel range
    if config.start_channel < 0 or config.start_channel + 3 >= actual_channels:
        raise HTTPException(400, f"Invalid start_channel. Only {actual_channels} channels available (must be 0-{actual_channels-4})")
    
    if config.start_channel % 4 != 0:
        raise HTTPException(400, "start_channel must be divisible by 4 (sample alignment)")
    
    # Check if already running
    if config.sample_id in sample_configs:
        raise HTTPException(400, f"Sample {config.sample_id} already running")
    
    # Store configuration
    sample_configs[config.sample_id] = config.dict()
    measurement_tasks[config.sample_id] = {
        pixel: {"status": "idle", "last_iv": None}
        for pixel in ['a', 'b', 'c', 'd']
    }
    
    print(f"[{rpi_id}] Started sample {config.sample_id} on channels {config.start_channel}-{config.start_channel+3}")
    print(f"[{rpi_id}] IV sweep interval: {config.sweep_interval_minutes} minutes")
    
    # Save Config.txt file
    save_config_file(config.sample_id, config)
    
    # Update Samples_Status.txt on Main PC
    update_samples_status_file()
    
    # Schedule periodic IV sweeps for this sample
    schedule.every(config.sweep_interval_minutes).minutes.do(
        perform_iv_sweep_for_sample, 
        sample_id=config.sample_id
    ).tag(config.sample_id)  # Tag allows us to cancel later
    
    # Perform initial IV sweep immediately
    background_tasks.add_task(perform_iv_sweep_for_sample, config.sample_id)
    
    return {
        "status": "started",
        "sample_id": config.sample_id,
        "channels": list(range(config.start_channel, config.start_channel + 4)),
        "sweep_interval_minutes": config.sweep_interval_minutes,
        "message": f"Sample measurement started with {config.sweep_interval_minutes} min interval"
    }


@app.post("/measurement/stop/{sample_id}")
async def stop_measurement(sample_id: str):
    """Stop measuring a sample and cancel its scheduled sweeps."""
    if sample_id not in sample_configs:
        raise HTTPException(404, f"Sample {sample_id} not found")
    
    # Cancel scheduled jobs for this sample
    schedule.clear(sample_id)
    
    del sample_configs[sample_id]
    del measurement_tasks[sample_id]
    
    print(f"[{rpi_id}] Stopped sample {sample_id}")
    
    # Update Samples_Status.txt on Main PC
    update_samples_status_file()
    
    return {
        "status": "stopped",
        "sample_id": sample_id
    }


@app.get("/measurement/{sample_id}")
async def get_measurement_status(sample_id: str):
    """Get status of a sample measurement."""
    if sample_id not in measurement_tasks:
        raise HTTPException(404, f"Sample {sample_id} not found")
    
    return {
        "sample_id": sample_id,
        "pixels": measurement_tasks[sample_id],
        "config": sample_configs.get(sample_id)
    }


# ==================== Measurement Functions ====================

def perform_iv_sweep_for_sample(sample_id: str):
    """Perform IV sweep for all 4 pixels of a sample."""
    if sample_id not in sample_configs:
        return
    
    config_dict = sample_configs[sample_id]
    config = MeasurementConfig(**config_dict)
    
    timestamp = datetime.now().strftime("%Y-%m-%d_%H-%M-%S")
    
    for pixel_idx, pixel_name in enumerate(['a', 'b', 'c', 'd']):
        try:
            ch_idx = config.start_channel + pixel_idx
            board_idx = ch_idx // 8
            local_ch = ch_idx % 8
            
            if board_idx >= len(board_manager.oboards):
                print(f"[{rpi_id}] ERROR: Board {board_idx} not available")
                continue
            
            channel = board_manager.oboards[board_idx].channel[local_ch]
            
            # Update status
            measurement_tasks[sample_id][pixel_name]["status"] = "measuring"
            
            print(f"[{rpi_id}] IV sweep: {sample_id}/{pixel_name} on channel {ch_idx}")
            
            # Perform IV sweep
            import numpy as np
            data = []
            
            for voltage in np.arange(config.start_voltage, 
                                    config.stop_voltage + config.voltage_step, 
                                    config.voltage_step):
                channel.set_voltage(voltage)
                time.sleep(config.settle_time)
                
                v = channel.read_voltage()
                i = channel.read_current()
                
                # Check current limit
                if abs(i * 1000) > config.current_limit:
                    print(f"[{rpi_id}] Current limit exceeded: {sample_id}/{pixel_name}")
                    break
                
                data.append({
                    "timestamp": datetime.now().isoformat(),
                    "voltage": v,
                    "current": i,
                    "power": v * i
                })
            
            channel.set_voltage(0)  # Safety
            
            # Save IV data locally
            local_file = save_iv_data_locally(sample_id, pixel_name, timestamp, data)
            
            # Transfer to Main PC
            transfer_file_to_main_pc(sample_id, pixel_name, local_file)
            
            # Update status
            measurement_tasks[sample_id][pixel_name]["status"] = "idle"
            measurement_tasks[sample_id][pixel_name]["last_iv"] = timestamp
            
        except Exception as e:
            print(f"[{rpi_id}] ERROR in IV sweep {sample_id}/{pixel_name}: {e}")
            measurement_tasks[sample_id][pixel_name]["status"] = "error"


def update_samples_status_file():
    """Create/update Samples_Status.txt on Main PC showing all active samples."""
    try:
        # Create status content
        status_content = f"=== OctoBoard Samples Status ===\n"
        status_content += f"RPi ID: {rpi_id}\n"
        status_content += f"Updated: {datetime.now().strftime('%Y-%m-%d %H:%M:%S')}\n"
        status_content += f"Active Samples: {len(sample_configs)}/{SAMPLES_PER_RPI}\n"
        status_content += f"\n"
        
        if sample_configs:
            status_content += f"{'Sample ID':<20} {'Channels':<15} {'Interval':<15} {'Status'}\n"
            status_content += f"{'-'*70}\n"
            
            for sample_id, config_dict in sample_configs.items():
                config = MeasurementConfig(**config_dict)
                channels = f"{config.start_channel}-{config.start_channel+3}"
                interval = f"{config.sweep_interval_minutes} min"
                status = "Running"
                status_content += f"{sample_id:<20} {channels:<15} {interval:<15} {status}\n"
        else:
            status_content += "No active samples\n"
        
        # Save locally
        local_path = Path(f"/tmp/octoboard_{rpi_id}/Samples_Status.txt")
        local_path.parent.mkdir(parents=True, exist_ok=True)
        with open(local_path, 'w') as f:
            f.write(status_content)
        
        # Transfer to Main PC root folder
        main_pc_url = f"http://{MAIN_PC_IP}:{MAIN_PC_PORT}/upload"
        print(f"[{rpi_id}] Transferring Samples_Status.txt to {main_pc_url}...")
        with open(local_path, 'rb') as f:
            files = {'file': (f'{rpi_id}_Samples_Status.txt', f, 'text/plain')}
            data = {
                'rpi_id': rpi_id,
                'sample_id': '',  # Status file is at root level
                'pixel': ''
            }
            response = requests.post(main_pc_url, files=files, data=data, timeout=FILE_TRANSFER_TIMEOUT)
            print(f"[{rpi_id}] Samples_Status.txt transfer response: {response.status_code}")
            if response.status_code == 200:
                print(f"[{rpi_id}] Updated Samples_Status.txt on Main PC")
            else:
                print(f"[{rpi_id}] Samples_Status.txt transfer failed: {response.status_code} - {response.text}")
    except Exception as e:
        print(f"[{rpi_id}] Failed to update Samples_Status.txt: {e}")
        import traceback
        traceback.print_exc()


def save_config_file(sample_id: str, config: MeasurementConfig):
    """Save Config.txt in the sample folder."""
    local_dir = Path(f"/tmp/octoboard_{rpi_id}/IV/{sample_id}")
    local_dir.mkdir(parents=True, exist_ok=True)
    
    config_path = local_dir / "Config.txt"
    
    with open(config_path, 'w') as f:
        f.write(f"Sample ID: {sample_id}\n")
        f.write(f"RPI ID: {rpi_id}\n")
        f.write(f"Start Channel: {config.start_channel}\n")
        f.write(f"Channels Used: {config.start_channel} to {config.start_channel + 3}\n")
        f.write(f"Cell Area: {config.cell_area} cm²\n")
        f.write(f"Current Limit: {config.current_limit} mA\n")
        f.write(f"Start Voltage: {config.start_voltage} V\n")
        f.write(f"Stop Voltage: {config.stop_voltage} V\n")
        f.write(f"Voltage Step: {config.voltage_step} V\n")
        f.write(f"Settle Time: {config.settle_time} s\n")
        f.write(f"Measurement Type: {config.measurement_type}\n")
        f.write(f"IV Sweep Interval: {config.sweep_interval_minutes} minute(s)\n")
        f.write(f"Started: {datetime.now().strftime('%Y-%m-%d %H:%M:%S')}\n")
    
    print(f"[{rpi_id}] Created Config.txt for {sample_id}")
    
    # Transfer to Main PC
    try:
        main_pc_url = f"http://{MAIN_PC_IP}:{MAIN_PC_PORT}/upload"
        print(f"[{rpi_id}] Transferring Config.txt to {main_pc_url}...")
        with open(config_path, 'rb') as f:
            files = {'file': (config_path.name, f, 'text/plain')}
            data = {
                'rpi_id': rpi_id,
                'sample_id': sample_id,
                'pixel': ''  # Config is at sample level, not pixel level
            }
            response = requests.post(main_pc_url, files=files, data=data, timeout=FILE_TRANSFER_TIMEOUT)
            print(f"[{rpi_id}] Config.txt transfer response: {response.status_code}")
            if response.status_code == 200:
                print(f"[{rpi_id}] Transferred Config.txt → Main PC")
            else:
                print(f"[{rpi_id}] Config.txt transfer failed: {response.status_code} - {response.text}")
    except Exception as e:
        print(f"[{rpi_id}] Config.txt transfer error: {e}")
        import traceback
        traceback.print_exc()


def save_iv_data_locally(sample_id: str, pixel: str, timestamp: str, data: List[Dict]) -> Path:
    """Save IV data to local file."""
    import csv
    
    # Create directory structure
    local_dir = Path(f"/tmp/octoboard_{rpi_id}/IV/{sample_id}/{pixel}")
    local_dir.mkdir(parents=True, exist_ok=True)
    
    # Save file
    filename = f"IV_{timestamp}.csv"
    filepath = local_dir / filename
    
    # Write CSV using csv module instead of pandas
    if data:
        with open(filepath, 'w', newline='') as f:
            writer = csv.DictWriter(f, fieldnames=data[0].keys())
            writer.writeheader()
            writer.writerows(data)
    
    print(f"[{rpi_id}] Saved: {filepath}")
    return filepath


def transfer_file_to_main_pc(sample_id: str, pixel: str, filepath: Path):
    """Transfer IV file to Main PC via HTTP POST."""
    try:
        main_pc_url = f"http://{MAIN_PC_IP}:{MAIN_PC_PORT}/upload"
        
        with open(filepath, 'rb') as f:
            files = {'file': (filepath.name, f, 'text/csv')}
            data = {
                'rpi_id': rpi_id,
                'sample_id': sample_id,
                'pixel': pixel
            }
            
            response = requests.post(
                main_pc_url,
                files=files,
                data=data,
                timeout=FILE_TRANSFER_TIMEOUT
            )
            
            if response.status_code == 200:
                print(f"[{rpi_id}] Transferred: {sample_id}/{pixel} → Main PC")
            else:
                print(f"[{rpi_id}] Transfer failed: {response.status_code}")
                
    except Exception as e:
        print(f"[{rpi_id}] Transfer error: {e}")


def test_main_pc_connection() -> bool:
    """Test if Main PC is reachable."""
    try:
        response = requests.get(
            f"http://{MAIN_PC_IP}:{MAIN_PC_PORT}/ping",
            timeout=2
        )
        return response.status_code == 200
    except:
        return False


def is_channel_active(ch_idx: int) -> bool:
    """Check if a channel is currently assigned to a sample."""
    for sample_id, config in sample_configs.items():
        start_ch = config['start_channel']
        if start_ch <= ch_idx < start_ch + 4:
            return True
    return False


def get_assigned_sample(start_ch: int) -> Optional[str]:
    """Get sample ID assigned to a channel slot."""
    for sample_id, config in sample_configs.items():
        if config['start_channel'] == start_ch:
            return sample_id
    return None


# ==================== Server Launcher ====================

if __name__ == "__main__":
    port = int(os.environ.get('API_PORT', '8001'))
    uvicorn.run(app, host="0.0.0.0", port=port)

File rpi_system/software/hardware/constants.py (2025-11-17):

"""Global constants used across the MPP tracker system."""

import numpy as np
import os

# ==================== SIMULATION MODE ====================
# Set to True for development without Raspberry Pi hardware
# Set to False when running on actual hardware
# This can be overridden via environment variable or command-line argument
SIMULATION_MODE = os.environ.get('OCTOBOARD_SIMULATION', 'False').lower() in ('true', '1', 'yes')
# =========================================================

# Board Manager Configuration
BOARD_DEFAULT_I2C_NUM = 1
BOARD_DEFAULT_OFFSET_RANGE = range(0, 12)  # 12 Octoboards = 96 channels
BOARD_DEFAULT_ITERATIONS = 10
BOARD_DEFAULT_INTERVAL = 0.001  # seconds

# System Configuration
TOTAL_BOARDS_PER_RPI = 12  # 12 Octoboards per Raspberry Pi
TOTAL_CHANNELS_PER_RPI = 96  # 12 × 8 = 96 channels
SAMPLES_PER_RPI = 24  # 96 channels ÷ 4 pixels = 24 samples
PIXELS_PER_SAMPLE = 4  # Each sample has 4 pixels: a, b, c, d

# I2C Device Base Addresses
I2C_BASE_MUX = 32    # Base address for MCP23017 multiplexer
I2C_BASE_ADC = 72    # Base address for ADS1115 ADC
I2C_BASE_DAC_0 = 96  # Base address for first MCP4728 DAC
I2C_BASE_DAC_1 = 97  # Base address for second MCP4728 DAC

# List of base addresses in order: MUX, ADC, DAC_0, DAC_1
I2C_BASE_ADDRESSES = [I2C_BASE_MUX, I2C_BASE_ADC, I2C_BASE_DAC_0, I2C_BASE_DAC_1]

# Address offset multipliers for different devices
I2C_OFFSET_MULTIPLIER = {
    I2C_BASE_MUX: 1,    # MUX uses 1x offset
    I2C_BASE_ADC: 1,    # ADC uses 1x offset
    I2C_BASE_DAC_0: 2,  # DACs use 2x offset
    I2C_BASE_DAC_1: 2   # DACs use 2x offset
}


# Softdac Configuration
SOFTDAC_MUX_PINS = [8, 9, 10, 11]  # Multiplexer pins used for gain control
SOFTDAC_DEFAULT_VREF = 5.0          # Default reference voltage (V)

# Gain Configurations
SOFTDAC_GAIN_VOLTAGES = np.array([
    0.04242424,  # Gain level 0
    0.09060606,  # Gain level 1
    0.13303030,  # Gain level 2
    0.19878788,  # Gain level 3
    0.24121212,  # Gain level 4
    0.28878788,  # Gain level 5
    0.33030303,  # Gain level 6
    0.42030303   # Gain level 7
])

# Pin state configurations for each gain level
# Format: [PIN_8, PIN_9, PIN_10, PIN_11]
SOFTDAC_GAIN_REGISTERS = np.array([
    [0, 0, 0, 0],  # Gain level 0
    [1, 0, 0, 0],  # Gain level 1
    [0, 1, 0, 0],  # Gain level 2
    [1, 1, 0, 0],  # Gain level 3
    [0, 0, 1, 0],  # Gain level 4
    [1, 0, 1, 0],  # Gain level 5
    [0, 1, 1, 0],  # Gain level 6
    [1, 1, 1, 0],  # Gain level 7
    [0, 0, 0, 1]   # Gain level 8
])

# General Board Configuration
CHANNELS_PER_BOARD = 8
MAX_CHANNELS_PER_DAC = 4
I2C_DAC_CHANNELS = ['channel_a', 'channel_b', 'channel_c', 'channel_d']

# Channel Configuration
CHANNEL_DEFAULT_SHUNT_RESISTANCE = 20     # Default shunt resistance (Ohms)
CHANNEL_VOLTAGE_LIMITS = (0, 1.2)         # Default voltage limits (V)
CHANNEL_INITIAL_VOLTAGE = 0.0             # Starting voltage for MPP tracking (V)
CHANNEL_INITIAL_DIRECTION = 1             # Initial direction for MPP tracking
CHANNEL_INITIAL_POWER = 0.0               # Initial power value
CHANNEL_INITIAL_VOLTAGE_STEP = 0.05       # Initial voltage step size (V)
CHANNEL_MAX_VOLTAGE_STEP = 0.2            # Maximum voltage step size (V)
CHANNEL_MIN_VOLTAGE_STEP = 2e-3           # Minimum voltage step size (V)

# ADC Configuration for Channel
CHANNEL_VOLTAGE_GAIN = 2                  # Default gain for voltage measurements
CHANNEL_CURRENT_GAIN = 16                 # Default gain for current measurements; Note: this eems to be used as data rate for some reason. (oboard.py)
# CHANNEL_CURRENT_GAIN = 2

CHANNEL_ADC_SETTLE_TIME = 0.01           # ADC settling time (seconds)

# MPP Tracking Parameters
CHANNEL_POWER_INCREASE_FACTOR = 1.1       # Factor to increase step size when power increases
CHANNEL_POWER_DECREASE_FACTOR = 0.3       # Factor to decrease step size when power decreases

# DAC Configuration
CHANNEL_DAC_GAIN = 1                      # Default DAC gain
# CHANNEL_DAC_VOLTAGE_SCALE = 2**16 / 8    # DAC voltage scaling factor (16-bit, 0-4V range)
CHANNEL_DAC_VOLTAGE_SCALE = 31.25e-6

# I/O Configuration
CHANNEL_DATA_DIRECTORY = "data"           # Directory for MPP tracking data
CHANNEL_IV_DIRECTORY = "IV"               # Directory for IV sweep data
CHANNEL_DEFAULT_HEADER = 'timestamp,measured_voltage,measured_current,dac_value,adc_gain_v,adc_gain_c'

# IV Sweep Configuration
CHANNEL_IV_START_VALUE = 0.0               # Default start value for IV sweep (V)
CHANNEL_IV_END_VALUE = 1.2                 # Default end value for IV sweep (V)
CHANNEL_IV_STEP_SIZE = 0.01                # Default step size for IV sweep (V)

# IV Sweep Scheduling (DEPRECATED - now controlled per-sample from Main PC)
IV_SWEEP_INTERVAL_HOURS = 1                # DEFAULT: 1 hour (60 minutes)
IV_SWEEP_INTERVAL_SECONDS = 3600           # DEFAULT: 1 hour = 3600 seconds
# NOTE: Actual interval is set by Main PC via sweep_interval_minutes parameter (1-1000 min)
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

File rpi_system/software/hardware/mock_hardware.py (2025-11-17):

"""
Mock hardware modules for development without Raspberry Pi.
This allows development and testing on Windows or any platform without actual hardware.
"""

import threading
import numpy as np
from datetime import datetime

# ==================== Mock busio ====================
class MockI2C:
    """Mock I2C bus for development without hardware."""
    
    def __init__(self, scl=None, sda=None, frequency=400000):
        self._lock = threading.RLock()
        self._devices = {}  # Simulated devices on the bus
        print(f"[MOCK] I2C initialized (simulated)")
    
    def try_lock(self):
        """Try to grab the lock."""
        return self._lock.acquire(blocking=False)
    
    def unlock(self):
        """Release the lock."""
        self._lock.release()
    
    def scan(self):
        """Return list of simulated I2C device addresses."""
        # Simulate 4 boards with proper address offsets
        devices = []
        for offset in range(4):
            devices.extend([
                32 + offset * 1,   # MUX
                72 + offset * 1,   # ADC
                96 + offset * 2,   # DAC_0
                97 + offset * 2,   # DAC_1
            ])
        print(f"[MOCK] I2C scan found devices: {devices}")
        return devices
    
    def writeto(self, address, buffer, start=0, end=None):
        """Mock write to I2C device."""
        pass
    
    def readfrom_into(self, address, buffer, start=0, end=None):
        """Mock read from I2C device."""
        pass


# ==================== Mock Adafruit MCP4728 (DAC) ====================
class MockMCP4728Channel:
    """Mock single channel of MCP4728 DAC."""
    
    def __init__(self):
        self._value = 0
        self._raw_value = 0
        self.gain = 1
    
    @property
    def value(self):
        return self._value
    
    @value.setter
    def value(self, val):
        self._value = val
        self._raw_value = val
    
    @property
    def raw_value(self):
        return self._raw_value


class MockMCP4728:
    """Mock MCP4728 4-channel DAC."""
    
    def __init__(self, i2c, address=0x60):
        self.address = address
        self.channel_a = MockMCP4728Channel()
        self.channel_b = MockMCP4728Channel()
        self.channel_c = MockMCP4728Channel()
        self.channel_d = MockMCP4728Channel()
        print(f"[MOCK] MCP4728 DAC initialized at address {address}")


# ==================== Mock Adafruit ADS1115 (ADC) ====================
class MockADS1115:
    """Mock ADS1115 16-bit ADC."""
    
    def __init__(self, i2c, gain=1, data_rate=128, address=0x48):
        self.address = address
        self.gain = gain
        self.data_rate = data_rate
        self.bits = 16
        self._simulated_voltage = 0.0
        self._simulated_current = 0.0
        print(f"[MOCK] ADS1115 ADC initialized at address {address}")
    
    def read(self, pin_setting):
        """Simulate ADC reading with realistic solar cell behavior."""
        # Simulate a solar cell with some variation
        # Return 16-bit integer value
        
        # Differential pairs: P0-P1 is voltage, P2-P3 is current
        if pin_setting == 0x0000:  # P0-P1 (voltage)
            # Simulate voltage reading (0-1.2V typical for solar cell)
            voltage = 0.8 + np.random.normal(0, 0.01)  # ~0.8V ± noise
            # Convert to 16-bit ADC value
            lsb = 4.096 / (1 << 15)  # For gain=1
            return int(voltage / lsb)
        
        elif pin_setting == 0x0003:  # P2-P3 (current via shunt)
            # Simulate current reading (voltage across 20Ω shunt)
            current_amps = 0.01 + np.random.normal(0, 0.0001)  # ~10mA ± noise
            voltage_across_shunt = current_amps * 20  # V = I * R
            lsb = 4.096 / (1 << 15)
            return int(voltage_across_shunt / lsb)
        
        return 0


# Mock pin settings for ADS1115
class MockPin:
    def __init__(self, value):
        self.value = value

P0 = MockPin(0)
P1 = MockPin(1)
P2 = MockPin(2)
P3 = MockPin(3)

_ADS1X15_DIFF_CHANNELS = {
    (P0, P1): 0x0000,
    (P0, P3): 0x0001,
    (P1, P3): 0x0002,
    (P2, P3): 0x0003,
}

_ADS1X15_PGA_RANGE = {
    2/3: 6.144,
    1: 4.096,
    2: 2.048,
    4: 1.024,
    8: 0.512,
    16: 0.256
}


# ==================== Mock Adafruit MCP23017 (I/O Expander) ====================
class MockMCP23017Pin:
    """Mock single pin of MCP23017."""
    
    def __init__(self, pin_num):
        self.pin_num = pin_num
        self._value = 0
    
    def switch_to_output(self, value=False):
        """Set pin as output with initial value."""
        self._value = int(value)
    
    def switch_to_input(self):
        """Set pin as input."""
        pass
    
    @property
    def value(self):
        return self._value
    
    @value.setter
    def value(self, val):
        self._value = int(val)
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

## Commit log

2025-11-17 v2.0: Production-ready system with configurable intervals and auto-detection
    - Added configurable IV sweep intervals (1-1000 minutes per sample)
    - Implemented persistent state management with status files
    - Added automatic hardware detection (1-12 Octoboards per RPi)
    - Optimized dashboard with pagination for 288+ channels
    - Created production deployment guides (PRODUCTION_DEPLOYMENT.md, RPi_BEGINNER_GUIDE.md)
    - Added beginner's guide for Raspberry Pi setup
    - Fixed channel assignment to prevent conflicts
    - Updated file receiver to handle config and status files
    - Added systemd service configuration for auto-start
    - Improved dashboard performance with caching and form optimization
    - Added star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
    [Assembly.iam, Bauteil4.ipt, Bauteil5.ipt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]
2025-12-02 Update Raspberry Pi connection details and improve data handling
    - Added detailed instructions for connecting Raspberry Pi from Windows.
    - Updated RPi configuration in dashboard.py for direct Ethernet connection.
    - Changed data saving method in api_server.py to use csv module instead of pandas.
    - Introduced check_imports.py to verify Adafruit ADS1x15 library imports.
    - Adjusted channel.py to define pin constants for newer library versions.
    - Modified start_rpi.sh to reflect new Main PC IP address for direct connection.
2025-12-02 Add comprehensive Raspberry Pi setup guide for dual configuration
